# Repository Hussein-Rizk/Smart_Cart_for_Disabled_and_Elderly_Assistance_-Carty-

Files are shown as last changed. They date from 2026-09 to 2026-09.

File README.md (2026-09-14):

# 🛒 Carty — Smart Follow-Me Cart for Disabled & Elderly Assistance

<p align="center">
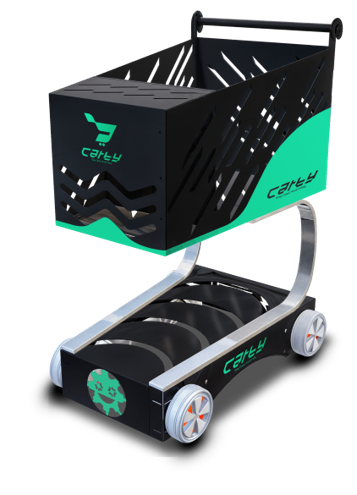
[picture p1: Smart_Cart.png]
  
</p>

<p align="center">
  <b>Stay Close, Move Freely.</b>
</p>

**Graduation Project II — 2025**  
**Mechatronics Engineering Program — Faculty of Engineering, Mansoura University**

**Official Project Title:**  
*Automated “Follow-Me” Cart Using AI and Computer Vision for Disabled and Elderly Assistance*

Carty is an **AI-powered assistive smart cart** designed to improve independence, safety, and convenience for elderly people and individuals with physical disabilities. The system combines **computer vision, gesture recognition, obstacle detection, embedded control, custom electronics, mechanical design, and a mobile-app interface** in a single multidisciplinary prototype.

The cart can recognize its user, respond to hand gestures, follow autonomously, detect nearby obstacles, and also support manual control. A companion app concept extends the system with cart control, battery monitoring, store navigation, and cart-content tracking.

---

## 🎯 Project Goal

The goal was to create a **hands-free mobility and carrying assistant** that reduces the physical effort required for everyday tasks while remaining safe and intuitive to use.

Core objectives included:

- autonomous user following
- hand-gesture interaction
- real-time obstacle detection and avoidance
- manual control when needed
- robust and portable mechanical design
- real-time AI processing on embedded hardware
- modular electronics and custom PCB integration
- battery-powered operation
- user monitoring and control through a mobile interface

---

## ✨ Key Features

### 🤖 AI-Powered Gesture Recognition

The cart uses a camera and **MediaPipe** hand tracking to detect hand landmarks and interpret gestures.

Examples documented in the project include:

```text
Open / Follow gesture → Follow the user
Stop gesture          → Stop the cart
```

MediaPipe was selected because it is lightweight, optimized for real-time operation, and provides **21 hand landmarks** for gesture classification.

### 👕 User / Vest Recognition

A **YOLOv8** model was developed for visual recognition, including vest/clothing detection used to help identify and track the intended user.

The development process included:

```text
Dataset Collection
        ↓
Annotation
        ↓
YOLOv8 Fine-Tuning
        ↓
Data Augmentation
        ↓
Real-Time Testing
        ↓
Jetson Nano Deployment
```

### 👁️ Obstacle Detection & Avoidance

The cart combines:

- IR sensors
- ultrasonic sensors
- camera-based perception

to detect obstacles and improve safe navigation.

### 🎮 Manual Control

Manual control is supported through a **joystick / Arduino Nano control layer**, allowing the system to be operated directly when autonomous control is not appropriate.

### 📱 Mobile App / UI

The documented Carty mobile-app interface includes:

- user registration
- recognition screen
- store mapping
- manual cart control
- automatic/manual mode selection
- speed selection
- battery monitoring
- cart-content monitoring
- item count and cost display
- remote cart control

UI documentation is available in the `UI/` folder.

---

# 🧠 System Architecture

```text
                         ┌─────────────────────┐
                         │       Camera        │
                         └─────────┬───────────┘
                                   │
                                   ▼
                         ┌─────────────────────┐
                         │  NVIDIA Jetson Nano │
                         │ MediaPipe / YOLOv8  │
                         │ Computer Vision     │
                         └─────────┬───────────┘
                                   │ UART
                                   ▼
                         ┌─────────────────────┐
                         │    Arduino Nano     │
                         │    ATmega328P       │
                         └──────┬───────┬──────┘
                                │       │
                   ┌────────────┘       └─────────────┐
                   ▼                                  ▼
          ┌────────────────┐                ┌─────────────────┐
          │ IR / Ultrasonic│                │  Motor Drivers  │
          │    Sensors     │                └────────┬────────┘
          └────────────────┘                         │
                                                   ▼
                                           ┌──────────────┐
                                           │ Wiper Motors │
                                           │   + Wheels   │
                                           └──────────────┘
```

The embedded software also follows a layered structure:

```text
Application Layer
      ↓
HAL — Hardware Abstraction Layer
      ↓
MCAL — Microcontroller Abstraction Layer
```

The project documentation describes UART communication at **9600 baud** between embedded subsystems.

---

# ⚙️ Mechanical Design

The cart was developed through multiple SolidWorks iterations before the final design was selected.

<p align="center">
  
</p>

The design consists of:

- upper storage body
- lower drive chassis
- component enclosure
- curved structural linking members
- threaded support rods
- four wheels
- four wiper motors
- custom motor-wheel couplers
- integrated camera mounting area
- hardware and wiring passages

### Main Materials

| Section | Material / Purpose |
|---|---|
| Lower chassis | Galvanized sheet metal for load-bearing strength |
| Upper side panels | Sheet metal for structural stiffness |
| Electronics enclosure | Wood for lightweight electrical insulation |
| Linking members | Steel for stability and support |
| Couplers | Machined steel |
| Handle | Wood |

The project book documents an overall cart size of approximately **600 × 820 mm** and a prototype mass of approximately **20 kg**.

---

## 🚗 Drive System

The cart uses **four wiper motors**, selected for their high torque, availability, durability, and cost effectiveness.

Documented motor characteristics include:

```text
Rated torque       ≈ 20 Nm per motor
Operating voltage  = 12 V
Operating current  ≈ 4–5 A under load
Number of motors   = 4
```

The design study estimated a maximum supported operating mass of approximately:

```text
62.7 kg
```

for the selected drive configuration.

---

# 🔌 Hardware

Major hardware used in the prototype includes:

| Component | Function |
|---|---|
| NVIDIA Jetson Nano | AI and computer-vision processing |
| Arduino Nano | Motor/sensor control and embedded coordination |
| Camera | User tracking and gesture recognition |
| IR Sensors | Short-range obstacle detection |
| Ultrasonic Sensors | Distance measurement / obstacle detection |
| Wiper Motors | Cart movement |
| Motor Drivers | Direction and PWM speed control |
| Joystick | Manual control |
| Battery | Mobile power source |
| Custom PCBs | Motor control, safety, and control integration |

### Jetson Nano

The project uses the NVIDIA Jetson Nano as the main AI computing platform.

```text
GPU:      128-core Maxwell
Memory:   4 GB LPDDR4
I/O:      USB 3.0, CSI camera, GPIO
```

### Camera

```text
Resolution:      1920 × 1080
Frame rate:      30 FPS
Field of view:   120°
```

### Sensors

**IR Sensors**
- 5 V operation
- short-range obstacle detection
- front and side placement

**Ultrasonic Sensors**
```text
Detection range: 2 cm – 4 m
Operating voltage: 5 V
Accuracy: ±3 mm
```

---

# 🧩 Custom PCB Design

Three custom PCBs were designed as part of the hardware system.

### 1. Motor Driver PCB
Responsible for:
- motor direction control
- PWM-based speed control
- interfacing the Arduino Nano with the motors
- high-current drive operation
- thermal management

### 2. Safety PCB
Designed for:
- protection mechanisms
- power management
- automatic disconnection during faults
- improved electrical reliability

### 3. Nano & Joystick PCB
Integrates:
- Arduino Nano
- joystick input
- motor-control signals
- sensor connections
- Jetson Nano communication
- power distribution
- real-time coordination

PCB design and simulation work included **EasyEDA** and **Proteus**.

---

# 💻 Software & Computer Vision

The software side combines embedded programming with real-time computer vision.

### Main Technologies

```text
Python
OpenCV
MediaPipe
YOLOv8 / Ultralytics
PyTorch
NumPy
Pandas
NVIDIA Jetson Nano
Arduino / ATmega328P
UART
```

### Computer-Vision Pipeline

```text
Camera Feed
    ↓
User / Clothing Recognition
    ↓
Hand Landmark Detection
    ↓
Gesture Classification
    ↓
Movement Command
    ↓
Jetson Nano
    ↓
UART
    ↓
Arduino Nano
    ↓
Motor Control
```

---

# 📱 Carty App UI

The `UI/` folder contains **8 UI images** and the full `ui.pdf`.

The interface concept covers:

### Registration & Recognition
- user registration
- front-camera recognition

### Cart Control
- forward / reverse / left / right
- low / medium / high speed
- manual mode
- automatic mode

### Store Mapping
- navigation interface
- destination / product search concept

### Battery Monitoring
- battery percentage
- remaining operating time

### Cart Content
- number of items
- used cart space
- total cost

The broader project documentation also describes synchronization and remote control through the mobile application.

---

# 🧪 Testing & Validation

The `Testing/` folder documents the project from subsystem testing to complete real-world operation.

### 1. `Assembly Final Project.mp4`
Shows the final mechanical assembly and integration of the cart.

### 2. `Computer Vision Test 1.mp4`
Tests the **Jetson Nano computer-vision / hand-gesture recognition pipeline**.

### 3. `Computer Vision Test 2.mp4`
Further tests gesture recognition and AI behavior under practical conditions.

### 4. `Practical Test.mp4`
Demonstrates the **complete smart cart working as an integrated system**, including recognition and physical cart movement.

Testing documented during the project also included:
- motor load testing
- PWM tuning
- sensor reliability testing
- different lighting environments
- battery/power testing
- hardware/software integration
- computer-vision validation

---

# 📚 Project Documentation

### `Carty.pdf` / `Carty.pptx`
The main project presentation covers:
- project overview and goals
- mechanical design
- hardware
- PCB design
- computer vision
- MediaPipe gesture recognition
- YOLOv8 recognition
- Jetson Nano environment
- embedded architecture
- mobile UI
- system testing

### `Graduation_Project_2_Book/`
Contains the complete Graduation Project II documentation, including:
- literature review
- mechanical design
- fabrication
- hardware implementation
- PCB design
- software integration
- AI and computer vision
- Jetson Nano setup
- ATmega328P architecture
- UI design
- testing
- project management
- cost analysis
- challenges
- future work

### `Add-Ons/`
Contains the final communication and exhibition material:
- banners
- poster
- brochure

---

# 👥 Team

<p align="center">
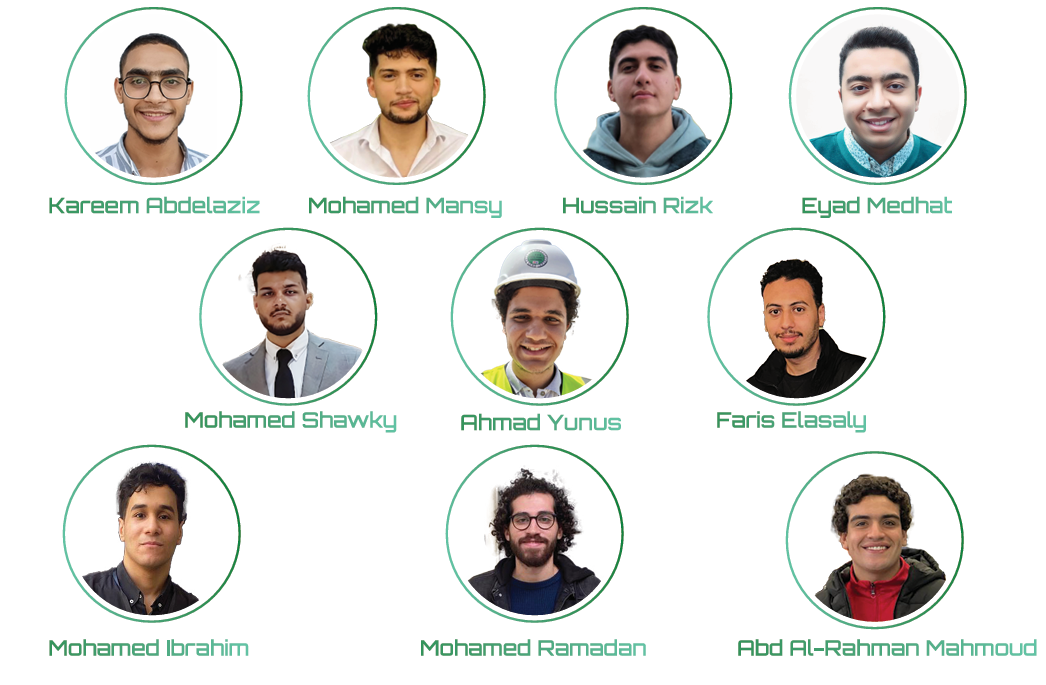
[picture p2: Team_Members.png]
  
</p>

**Project Team**

- Hussain Ahmed Ibrahim Abd Al-Aziz Rizk
- Eyad Medhat Mohamed Abdeljawad
- Mohamed Ahmed Fouad Ahmed Mansy
- Kareem Abdelaziz Ibrahim Abdallah
- Ahmad Mohammad Abdulmajid Yunus
- Mohamed Shawky Shawky Soliman
- Faris El-Sayed Nabeeh Elasaly
- Mohamed Ahmed Ramadan Abd Al-Atty
- Mohamed Ibrahim Abd El-Mawla
- Abd Al-Rahman Mahmoud El-Saeed Mohamed

**Supervisors**
- Prof. Sabry Saraya
- Eng. Ali El-Henidy

---

# 🎓 Project Information

**Project:** Carty — Automated Follow-Me Cart Using AI and Computer Vision for Disabled and Elderly Assistance  
**Type:** Graduation Project II  
**Year:** 2025  
**Academic Year:** 2024–2025  
**Program:** Mechatronics Engineering  
**Faculty:** Faculty of Engineering  
**University:** Mansoura University  

---

## 🚀 What This Project Demonstrates

- Mechanical CAD and fabrication
- Autonomous mobile robotics
- AI and computer vision
- Embedded systems
- Sensor integration
- Motor control
- Custom PCB design
- UART communication
- Edge AI deployment
- Human-machine interaction
- Mobile UI/UX design
- Practical integration and testing

> **Carty** demonstrates how mechanical engineering, embedded electronics, artificial intelligence, and computer vision can be integrated into an assistive robotic system designed around a real human need.

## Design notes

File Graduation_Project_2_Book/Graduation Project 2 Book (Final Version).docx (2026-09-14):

MANSOURA UNIVERSITY

FACULTY OF ENGINEERING

MECHATRONICS ENGINEERING PROGRAM

# Automated “Follow-Me” Cart Using AI and Computer Vision for Disabled and Elderly Assistance

Project Members ID number

Hussain Ahmed Ibrahim Abd Al-Aziz Rizk 803084842

Eyad Medhat Mohamed Abdeljawad 803089397

Mohamed Ahmed Fouad Ahmed Mansy 805771560

Kareem Abdelaziz Ibrahim Abdallah 803089481

Ahmad Mohammad Abdulmajid Yunus 803085462

Mohamed Shawky Shawky Soliman 803089402

Faris El-Sayed Nabeeh Elasaly 806096665

Mohamed Ahmed Ramadan Abd Al-Atty 803084384

Mohamed Ibrahim Abd El-Mawla 803089386

Abd Al-Rahman Mahmoud El-Saeed Mohamed 803084739

Supervisors:

Prof. Sabry Saraya

Eng. Ali El-Henidy

Academic Year: Fall 2024-2025

ACKNOWLEDGMENT

# We would like to express our deepest gratitude to Dr. Sabry Saraya for his continuous guidance and mentorship throughout the project.

# We also thank Eng. Ali El-Henidy for being the consultant and advisor we needed. The recommendations we received were of utmost value and dramatically improved the quality of our project.

# Special thanks to Eng. Ahmed Ibrahim and Eng. Mariam Helal and

# Eng. Khaled Waleed for volunteering their time and effort to assist us with their experience and exceptional quality. We cannot forget our friends and colleagues who provided us with their prior experiences; we thank every single one of you.

# Last but not least, we are profoundly grateful to our families. Their constant encouragement and support during our study years in this faculty have been the driving force behind every success we achieve. For that, we are truly thankful.

# ABSTRACT

The "Automated Follow-Me Cart Using AI and Computer Vision for Disabled and Elderly Assistance" addresses the growing need for accessible and intelligent mobility solutions in an aging society and for individuals with physical disabilities. This project integrates advanced computer vision and artificial intelligence to develop a smart cart capable of autonomously following its user based on intuitive hand gesture recognition. By leveraging deep learning algorithms, the system processes real-time video streams to identify user gestures, ensuring accurate and responsive tracking.

In addition to following the user, the cart incorporates state-of-the-art sensors for obstacle detection and avoidance, promoting safety in crowded or confined spaces. These sensors enable the cart to identify and navigate around obstacles such as people, furniture, or shelves while maintaining a consistent distance from the user. Furthermore, proximity and tracking sensors enhance the cart's ability to adapt to dynamic environments, ensuring reliable operation in diverse settings like homes, hospitals, and supermarkets.

The mechanical design emphasizes durability, portability, and efficiency. It is engineered with robust materials and optimized for lightweight construction, allowing easy maneuverability across various terrains. The integrated motors and power system ensure smooth and energy-efficient operation, while the modular design facilitates maintenance and scalability.

This project represents a multidisciplinary effort that combines mechanical engineering, computer vision, sensor integration, and artificial intelligence to create a user-friendly and accessible solution. By improving the independence and quality of life of disabled and elderly individuals, the Automated Follow-Me Cart contributes to a more inclusive society and demonstrates the transformative potential of modern engineering and technology.

TABLE OF CONTENTS

LIST OF FIGURES

Figure 1.1: Fields that Mechatronics Cover .......................................................................... 16

Figure 3.1: CAD Perspective ................................................................................................ 28

Figure 3.2: Real-View Perspective ........................................................................................ 28

Figure 3.3: Complete Design on SOLIDWORKS ................................................................ 30

Figure 3.4: Lower Part (Bottom View) ................................................................................. 31

Figure 3.5: Lower Part (Top View) ....................................................................................... 31

Figure 3.6: Upper Part of the Cart ......................................................................................... 31

Figure 3.7: The Linking Part ................................................................................................. 32

Figure 3.8: Side View of the Cart .......................................................................................... 32

Figure 3.9: Dimensions of the Cart ....................................................................................... 33

Figure 3.10: Components Used in the Design ....................................................................... 34

Figure 3.11: Back Side of the Upper Part .............................................................................. 35

Figure 3.12: Right Side of the Upper Part ............................................................................. 35

Figure 3.13: Left Side of the Upper Part ............................................................................... 35

Figure 3.14: Base of the Upper Part ...................................................................................... 36

Figure 3.15: Lower Part of the Cart ...................................................................................... 36

Figure 3.16: Connecting Links .............................................................................................. 37

Figure 3.17: Threaded Rods .................................................................................................. 37

Figure 3.18: The Wiper Motor .............................................................................................. 37

Figure 3.19: The Used Motor ................................................................................................ 40

Figure 3.20: Opening of the Component Box ....................................................................... 41

Figure 3.21: Closing of the Component Box ........................................................................ 41

Figure 3.22: The Handle of the Cart ..................................................................................... 43

Figure 3.23: The Wheel and the Coupler .............................................................................. 44

Figure 3.24: Other Side of the Wheel .................................................................................... 44

Figure 3.25: Dimensions of the Motor .................................................................................. 48

Figure 3.26: Wiring of the Lower Part .................................................................................. 49

Figure 4.1: Motor Driver Layout ........................................................................................... 60

Figure 4.2: 3D Model for Motor Driver ................................................................................ 61

Figure 4.3: Schematic View of Motor Driver ........................................................................ 61

Figure 4.4: IR Sensor Layout ................................................................................................ 57

Figure 4.5: Ultrasonic Sensor Layout ................................................................................... 57

Figure 4.6: Camera Used with Jetson Nano .......................................................................... 58

Figure 4.7: Arduino Nano ..................................................................................................... 59

Figure 4.8: Jetson Nano ......................................................................................................... 60

Figure 4.9: Royal Battery 12N9-BS ...................................................................................... 61

Figure 4.10: Jumpers and Wires ............................................................................................ 62

Figure 4.11: Safety PCB Layout ........................................................................................... 63

Figure 4.12: 3D Model for Safety PCB ................................................................................. 64

Figure 4.13: Schematic View for Safety PCB ....................................................................... 65

Figure 4.14: Joystick PCB Layout ........................................................................................ 66

Figure 4.15: 3d Model for Joystick PCB ............................................................................... 69

Figure 4.16: Schematic View for Joystick PCB .................................................................... 69

Figure 5.1: Jetson Nano Interface ......................................................................................... 81

Figure 5.2: ATmega328P ....................................................................................................... 83

Figure 5.3: Camera used with Jetson Nano ........................................................................... 83

Figure 5.4: IR Sensor Both Ways .......................................................................................... 84

Figure 5.5: YOLO V8 Logo .................................................................................................. 87

Figure 5.6: Object detection and classification ex1 .............................................................. 88

Figure 5.7: Object detection and classification ex2 .............................................................. 88

Figure 5.8: Mediapipe logo ................................................................................................... 92

Figure 5.9: Hand landmark points ......................................................................................... 93

Figure 5.10: Follow Me Signaling from Hand Gestures ....................................................... 95

Figure 5.11: Stop Signaling from Hand Gestures ................................................................. 95

Figure 5.12: Jetson Interface ............................................................................................... 103

Figure 5.13: Application Interface ...................................................................................... 109

Figure 5.14: Welcome Page ………..................................................................................... 109

Figure 5.15: Register and Log-in Page ……….................................................................... 110

Figure 5.16: Recognition Page ………................................................................................ 110

Figure 5.17: Store Mapping Page ………............................................................................ 111

Figure 5.18: Cart Control Page ………................................................................................ 112

Figure 5.19: Battery Monitoring Page ………..................................................................... 112

Figure 5.20: Cart Content Page ………............................................................................... 113

LIST OF TABLES

Table 6.1: Timeline Schedule ............................................................................................... 111

Table 6.1: Mechanical Costs ................................................................................................ 113

Table 6.2: Hardware Costs ................................................................................................... 114

Table 6.3: Software Costs .................................................................................................... 115

Table 6.4: Total Costs .......................................................................................................... 115

LIST OF ABBREVIATIONS

AI Artificial Intelligence

PCB Printed Circuit Board

AC Alternative Current

DC Direct Current

CAD Computer-Aided Design

IR Infrared

LIDAR Light Detection and Ranging

UART Universal asynchronous receiver / transmitter

BMS Battery Management System

GPU Graphics processing unit

Chapter 1 Introduction

# 1. Introduction

Mobility challenges faced by elderly individuals and those with physical disabilities can significantly impact their independence and overall quality of life. Activities that many take for granted, such as carrying groceries, moving objects, or navigating crowded spaces, can be overwhelming without proper assistance. Recognizing these challenges, our graduation project focuses on creating an intelligent solution—the Automated Follow-Me Cart Using AI and Computer Vision for Disabled and Elderly Assistance. This innovative cart is designed to enhance mobility, safety, and convenience for users, leveraging modern technologies to address a growing societal need.

The project was developed within the Mechatronics Engineering Department, a multidisciplinary field that integrates mechanics, electronics, computer science, and control engineering to design and create intelligent systems. The department fosters innovation by encouraging students to apply their knowledge to solve real-world problems, such as those tackled in this project. As shown in Figure 1.1, the Mechatronics Department emphasizes the intersection of these core engineering disciplines, making it an ideal environment for developing complex systems like the Automated Follow-Me Cart.

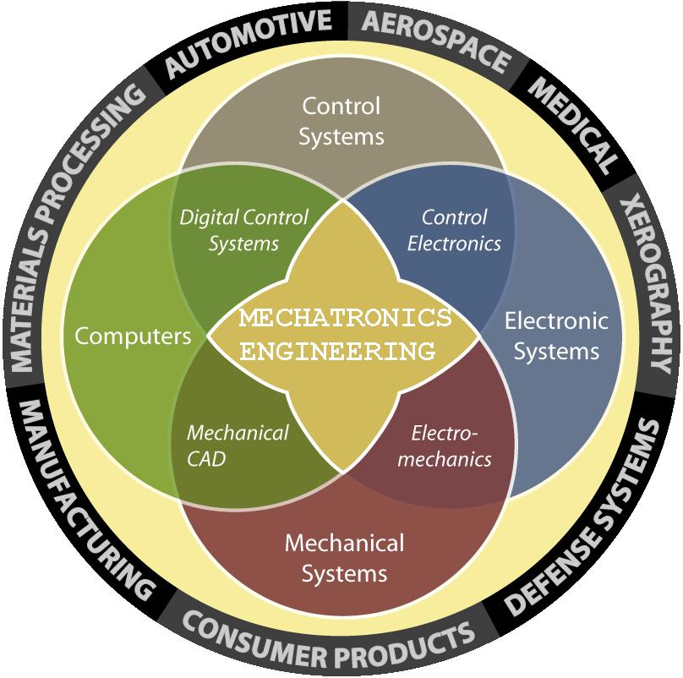
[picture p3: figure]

In this section, we will introduce the project’s goals, its key components, and the methodologies used in its design and implementation. We aim to provide a comprehensive overview of how the cart integrates advanced technologies to address practical challenges in assistive mobility.

Figure 1.1 Feilds that Mechatronics cover

## 1.1 Background and Motivation

The increasing global aging population and the prevalence of physical disabilities underscore the need for assistive technologies. According to recent studies, mobility aids such as wheelchairs and walkers have limitations in providing seamless, independent mobility. These devices often require significant human effort or assistance from caregivers. This creates a demand for smarter, more autonomous systems that can adapt to the user’s needs and environment.

Our project addresses these issues by combining artificial intelligence, computer vision, and mechanical design. The cart is specifically designed to follow the user autonomously, carry loads, and avoid obstacles in real-time. This blend of technologies ensures that users can move independently with minimal effort, promoting inclusivity and improving their quality of life.

## 1.2 Overview of the Project

The Automated Follow-Me Cart integrates multiple disciplines, including mechanical engineering, electronics, artificial intelligence, and computer vision. The primary objective is to create a cart that can follow a user intuitively, avoiding obstacles and ensuring smooth operation across different terrains.

The project’s mechanical structure was designed using SolidWorks, a powerful 3D CAD software widely used for engineering design and simulation. SolidWorks allowed the team to create a lightweight yet robust cart body that ensures durability and reliability. The design was optimized for weight distribution, easy maneuverability, and integration of electronic components such as sensors, motors, and processing units.

Key hardware components of the cart include:

- Four Motors: These provide stable and smooth movement, allowing the cart to traverse various surfaces with ease.
- Two Motor Drivers: Essential for precise control of the motors, ensuring the cart responds accurately to commands.
- Three Infrared (IR) Sensors: These sensors detect nearby obstacles and ensure real-time obstacle avoidance.
- A Camera: Used for real-time hand gesture recognition, the camera enables the cart to interpret and respond to user commands effectively.
- NVIDIA Jetson Platform: Serving as the AI computation unit, this platform processes the camera’s input for gesture recognition and controls the cart’s movement.
- Arduino Nano: A versatile microcontroller that handles auxiliary functions and integrates seamlessly with the other components.
- A Rechargeable Battery: Ensures the cart operates independently without the need for external power, providing portability and convenience.

## 1.3 Scope and Objectives

The project aims to address the following key objectives:

1. Mobility Assistance: Provide a hands-free, intuitive solution for elderly and disabled individuals to carry objects and navigate various environments.
2. Obstacle Avoidance: Ensure safety by integrating sensors and algorithms to detect and avoid obstacles in real-time.
3. Gesture Recognition: Implement an AI-based hand gesture recognition system for seamless user interaction.
4. Durability and Portability: Design a lightweight, robust mechanical structure capable of withstanding daily use across different terrains.
5. Energy Efficiency: Optimize power usage to ensure long battery life while maintaining performance.

By achieving these objectives, the project contributes to the growing field of assistive technology and promotes greater independence for users.

## 1.4 Significance of the Project

This project demonstrates the potential of engineering and technology to create solutions that address real-world challenges. The Automated Follow-Me Cart is more than just a mobility aid; it is a step toward a more inclusive society where technology bridges the gap for those with physical limitations. By combining AI, computer vision, and mechanical engineering, the cart offers a unique and practical solution to mobility challenges faced by a significant portion of the population.

Moreover, the cart’s modular and scalable design makes it a promising prototype for further development and commercialization. Its potential applications extend beyond individual users to include use cases in hospitals, care facilities, and retail environments, where similar functionality could improve operational efficiency and user experience.

## 1.5 Methodology Overview

The development of the Automated Follow-Me Cart involved a multidisciplinary approach, combining the following methodologies:

1. Mechanical Design: Using SolidWorks, the cart body was designed to optimize weight distribution, durability, and ease of assembly. Stress analysis and simulations were conducted to ensure structural integrity.
2. Hardware Integration: The cart includes multiple PCBs, motor drivers, IR sensors, a camera, and a Jetson AI platform. Each component was carefully selected and integrated to ensure compatibility and efficient operation.
3. Software Development: Custom algorithms for hand gesture recognition were developed and deployed on the NVIDIA Jetson platform. The Arduino Nano was programmed for auxiliary tasks such as motor control and sensor data processing.
4. Testing and Validation: The system was tested in various environments to ensure reliable operation. Real-world scenarios were simulated to validate the cart’s ability to follow the user, avoid obstacles, and respond to gestures.

By combining innovative design and advanced technologies, the Automated Follow-Me Cart showcases the power of engineering to solve real-world problems and improve lives.

## 1.6 Objectives

The primary objectives of the Automated “Follow-Me” Cart project are as follows:

1. Enhance Mobility Assistance: To design and build an intelligent, hands-free cart that autonomously follows users, allowing elderly and disabled individuals to carry groceries, personal items, or other objects with minimal effort, promoting independence in daily activities.
2. Real-Time Obstacle Avoidance: To integrate sensors (infrared and camera-based) and algorithms that enable the cart to detect and avoid obstacles in real-time, ensuring safe navigation through crowded or obstructed environments.
3. Implement Gesture Recognition for Seamless Interaction: To develop an AI-powered hand gesture recognition system using computer vision, enabling users to control the cart with simple, intuitive gestures without requiring physical touch or manual intervention.
4. Optimize Durability and Portability: To design a lightweight, yet robust mechanical structure capable of withstanding daily wear and tear across various terrains, ensuring the cart's longevity and ease of use in different environments.
5. Ensure Energy Efficiency and Long Battery Life: To optimize the cart's power consumption, enabling the system to operate for extended periods on a single charge while maintaining performance across all functions.
6. Provide a Scalable, Modular Design: To create a cart with a flexible design that can be further developed or adapted for other applications, including use in hospitals, care facilities, and retail spaces, extending its impact beyond individual mobility assistance.

By achieving these objectives, the Automated “Follow-Me” Cart will not only enhance the quality of life for elderly and disabled individuals but also serve as a practical solution that demonstrates the potential of modern technologies in assistive mobility.

Chapter 2 Literature Review

# 2. Literature Review

The development of the Automated “Follow-Me” Cart leverages several established and emerging technologies. This chapter reviews relevant research and existing technologies that form the foundation of the project. We examine the intersection of mobility assistance, robotics, artificial intelligence (AI), computer vision, and sensor technologies. By exploring these fields, we aim to better understand how various components can be integrated to design a functional, autonomous, and user-friendly assistive cart.

## 2.1 Mobility Aids and Assistive Technologies

The global aging population and the increasing prevalence of physical disabilities necessitate the development of mobility aids and assistive technologies. According to the World Health Organization (WHO), approximately 15% of the global population lives with a disability, and a significant portion of these individuals’ experiences mobility challenges (WHO, 2020). Traditional mobility aids, such as wheelchairs, walkers, and scooters, help improve mobility, but they come with limitations, such as dependency on manual operation, difficulties in navigating through crowded spaces, and lack of flexibility in adapting to various environments.

Research in assistive technologies has increasingly focused on reducing the dependency on caregivers and enhancing user autonomy. Early work in assistive robotics, such as the development of intelligent wheelchair systems, demonstrated that mobility could be enhanced through automation and sensor integration. For instance, studies by Akgün and Öztürk (2018) focused on developing autonomous navigation systems for electric wheelchairs, using sensors to detect obstacles and avoid collisions. These early developments laid the groundwork for the more advanced autonomous systems that are central to the Follow-Me Cart project.

## 2.2 Autonomous Mobile Robots (AMRs)

Autonomous mobile robots (AMRs) are robotic systems capable of performing tasks without human intervention. These robots are used in various industries, such as warehousing, agriculture, and healthcare. The concept of AMRs has evolved significantly, with advancements in AI, machine learning, and real-time data processing. According to Brooks (1986), the key challenge for AMRs lies in enabling them to navigate dynamic environments, such as crowded spaces or uneven terrain, while ensuring safety and reliability.

AMRs typically rely on a combination of sensors, including infrared (IR) sensors, ultrasonic sensors, cameras, and LIDAR (Light Detection and Ranging), to perceive their surroundings. The Follow-Me Cart integrates IR sensors for short-range obstacle detection and a camera for gesture recognition, both of which are critical for the cart’s autonomous functionality. Studies like those of Bhattacharya et al. (2017) on autonomous service robots emphasize the importance of sensor fusion for robust navigation in complex environments. The integration of multiple sensing modalities allows the Follow-Me Cart to detect and avoid obstacles effectively, even in crowded retail or indoor environments.

## 2.3 Hand Gesture Recognition

One of the most innovative aspects of the Follow-Me Cart is its use of AI-based hand gesture recognition. Gesture recognition systems have gained popularity in recent years due to their intuitive user interaction capabilities, particularly in applications where traditional input methods (e.g., buttons, joysticks) are less suitable. Gesture recognition leverages computer vision techniques to analyze and interpret hand movements, translating them into commands for various devices.

Several studies have explored the use of hand gesture recognition for controlling robots and assistive devices. A prominent approach uses machine learning algorithms to identify and classify gestures. For instance, Hossain et al. (2020) explored the use of deep learning techniques for recognizing hand gestures to control robotic arms. Similarly, work by Sadeghi et al. (2019) demonstrated the effectiveness of convolutional neural networks (CNNs) in recognizing hand gestures for controlling robotic systems in real-time. By using a camera for hand gesture recognition, the Follow-Me Cart employs these principles to create a seamless user interface, enabling individuals with mobility impairments to interact with the cart intuitively and without physical contact.

## 2.4 Obstacle Detection and Avoidance

Obstacle detection and avoidance are fundamental to ensuring the safety and smooth operation of autonomous systems, especially in dynamic environments. The Follow-Me Cart utilizes infrared (IR) sensors to detect nearby obstacles and adjust its path accordingly. Obstacle detection algorithms rely on real-time sensor data to calculate the cart’s position relative to obstacles and modify its movement.

Many autonomous vehicles and mobile robots use a combination of sensor types for enhanced perception. LIDAR and ultrasonic sensors are commonly used in large-scale autonomous systems, while smaller robots and assistive devices often rely on IR or ultrasonic sensors due to their affordability and simplicity. Work by Yang et al. (2018) in the field of mobile robotics highlights the importance of sensor fusion, combining data from multiple sensors to create a comprehensive map of the environment and enable reliable obstacle avoidance. The Follow-Me Cart integrates IR sensors to provide real-time data, allowing the cart to avoid obstacles such as people, shelves, or other objects in its path.

A key challenge in obstacle avoidance is ensuring the cart can operate in environments where obstacles are constantly changing, such as busy retail stores or crowded walkways. Dynamic path planning algorithms, such as those described by Kamal et al. (2019), can help the cart adapt to changing conditions by continually recalculating its optimal path in response to newly detected obstacles. These algorithms are a crucial component of the Follow-Me Cart’s software system.

## 2.5 AI and Machine Learning in Robotics

Artificial Intelligence (AI) and machine learning (ML) have revolutionized the field of robotics, enabling autonomous systems to learn from their environments, adapt to new situations, and improve performance over time. The Follow-Me Cart utilizes AI techniques for hand gesture recognition and to enhance its overall decision-making capabilities.

Machine learning algorithms, particularly deep learning models such as convolutional neural networks (CNNs), are widely used for image and pattern recognition tasks. In the context of gesture recognition, CNNs are particularly effective in identifying and classifying hand gestures based on visual input. Work by Sharma et al. (2020) demonstrated how CNNs could be used for robust gesture recognition, even in real-time applications with limited computing resources. The “Follow-Me” Cart uses the NVIDIA Jetson platform, which is optimized for running AI algorithms, to process the camera's input and interpret hand gestures. This allows the cart to follow user commands in a highly responsive and accurate manner.

Beyond gesture recognition, AI and machine learning can also be used to optimize the cart’s navigation. Reinforcement learning, a branch of machine learning focused on decision-making and reward optimization, can be applied to improve obstacle avoidance and path planning. This approach allows the cart to “learn” from its environment by continually refining its ability to navigate and follow the user in real-time.

## 2.6 Integration of Hardware and Software

The integration of hardware and software is a critical aspect of any robotics project. The Follow-Me Cart brings together various components, including the mechanical body, motors, sensors, microcontrollers, and AI computation unit, to create a seamless, functional system. The integration of these components requires careful consideration of compatibility, power requirements, and performance optimization.

The mechanical design of the cart, created using SolidWorks, ensures that the components are housed securely and that the cart is both lightweight and durable. The motors, motor drivers, and microcontrollers are selected based on their ability to work together efficiently, while the sensors and camera are chosen for their reliability in detecting obstacles and recognizing gestures.

The software system, which includes custom algorithms for hand gesture recognition, obstacle avoidance, and motor control, is deployed on the NVIDIA Jetson platform. This platform offers the computational power necessary for running AI-based algorithms in real-time. The Arduino Nano microcontroller handles auxiliary functions, such as motor control and sensor data processing, enabling smooth integration with the Jetson platform.

## 2.7 Conclusion

The literature review highlights the existing research and technologies that have contributed to the development of the Automated Follow-Me Cart. By combining insights from mobility assistance, autonomous robots, hand gesture recognition, and obstacle avoidance, the project aims to create a practical solution that addresses the mobility challenges faced by elderly and disabled individuals. The integration of AI, computer vision, and mechanical design offers a comprehensive approach to assistive technology, ensuring that the cart is both functional and user-friendly. As the project progresses, the insights from this literature review will guide the continued development of the system, with an emphasis on safety, usability, and efficiency.

Chapter 3 Mechanical Design

# 3. Mechanical Design

Figure 3.1 illustrates the CAD model of the Automated Follow-Me Cart, meticulously designed using SolidWorks. The model showcases the cart’s structural components, ensuring optimal weight distribution and durability. Each part has been designed and assembled to accommodate the hardware integration and user-specific functionalities, such as obstacle detection and gesture recognition modules. In contrast, Figure 3.2 presents the real-world perspective of the finalized project, demonstrating the seamless transition from the conceptual CAD design to the physical prototype. The real-view image highlights the successful implementation of the design, emphasizing its robust construction, compactness, and aesthetic appeal, which aligns with the project's goal of providing a practical and user-friendly mobility solution.

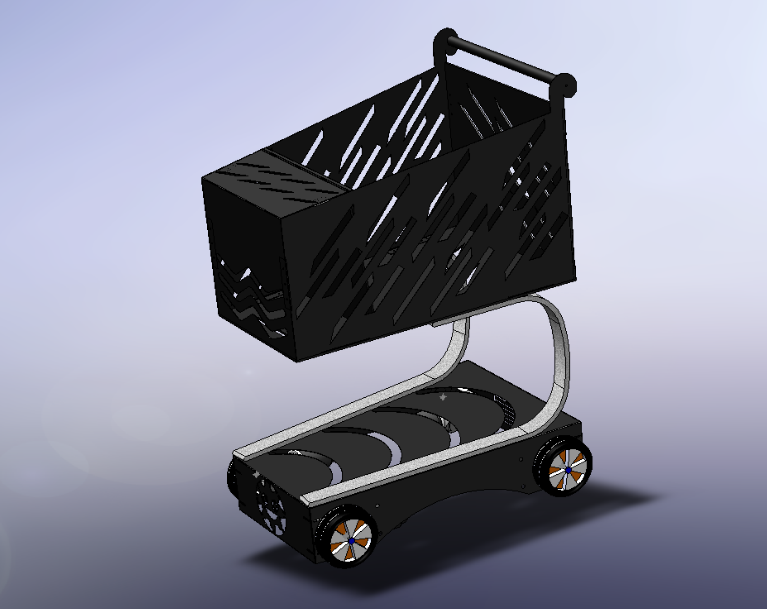
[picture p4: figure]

Figure 3.2 Real-View Perspective

Figure 3.1 CAD Perspective

The mechanical design sector is a critical component that encompasses the development and optimization of the cart's structural integrity and functionality. This chapter delves into the design principles, the parts used, materials selection, and fabrication methods employed to create a robust and efficient mechanical system.

Throughout the design process, we prioritized simplicity and efficiency, striving to minimize complexity while ensuring each component contributes effectively to the overall performance of the cart. The interplay of various mechanical parts, including the upper and lower bases, connecting flanges, and fasteners, was carefully considered to facilitate seamless operation and ease of assembly.

We faced several challenges, particularly in achieving precise angles and dimensions for the connecting components. These challenges required innovative solutions and iterative design adjustments to ensure structural stability and functionality. By employing advanced CAD software, we were able to visualize and refine our designs, leading to optimized mechanical solutions tailored to our project's specific needs.

In this chapter, we will explore the detailed design considerations, and the methodologies adopted to overcome design challenges, ultimately resulting in a cohesive and effective mechanical design.

## 3.1 The Design

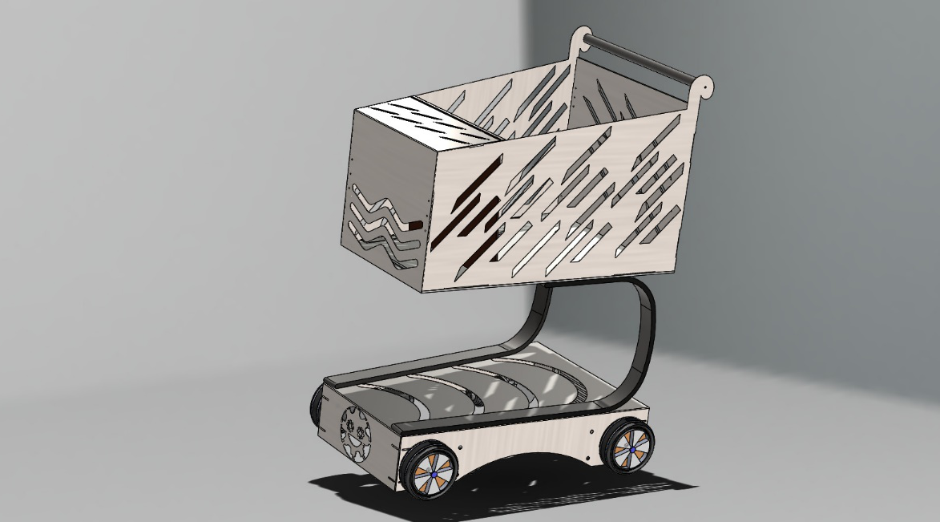
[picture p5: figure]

The complete design was developed using SolidWorks software, as shown in Figure 3.3, allowing our mechanical team to efficiently manage and finalize the entire design process. This CAD program enabled us to ensure that each component could be assembled seamlessly during fabrication. We carefully selected the appropriate dimensions for all parts and made necessary cuts or fixtures to guarantee the optimal functionality of the cart. The detailed CAD model in Figure 3.3 demonstrates the integration of structural and mechanical components, ensuring that the design meets the project's functional and practical requirements.

Figure 3.3 Complete Design on SOLIDWORKS

### 3.1.1 Material Selection for the Prototype

In the development of our prototype, we carefully selected a variety of materials tailored to the specific functions of each component, enhancing overall efficiency.

1. The lower section of the cart, as illustrated in Figure 3.4 (bottom view) and Figure 3.5 (top view), bears the majority of the weight and houses the motors and wheels. This section is constructed from sheet metal, a material chosen to ensure maximum strength and stability under heavy loads. The bottom view in Figure 3.4 highlights the placement of the motors and wheels, while the top view in Figure 3.5 provides a clear perspective of how the components are securely mounted to maintain structural integrity and efficient functionality.

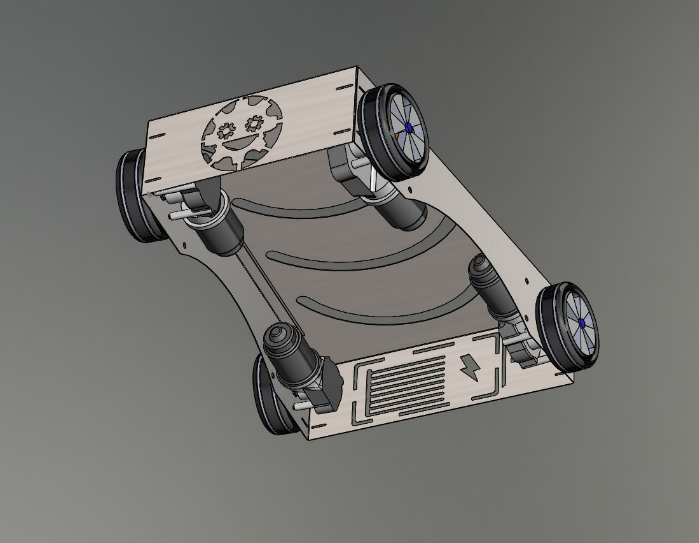
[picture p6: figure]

Figure 3.5 Lower part Top View

Figure 3.4 Lower part Bottom View

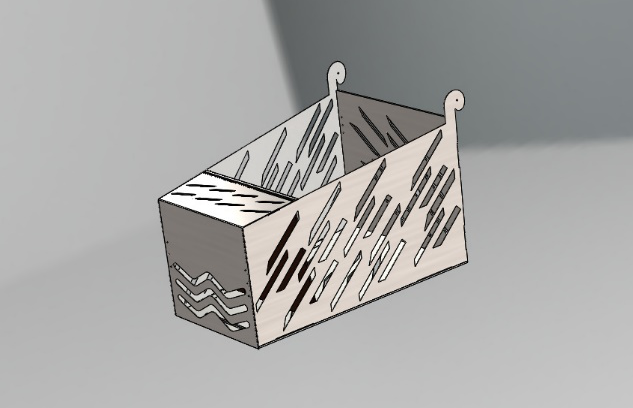
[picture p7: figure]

2. The upper section of the cart, as shown in Figure 3.6, is comprised of four distinct parts. The two side panels, made from sheet metal, provide additional stiffness to the structure, enhancing its durability. The remaining components are crafted from wood, offering a lightweight yet sturdy platform for securing the electrical components. This combination of materials ensures the safe and organized placement of electronic systems, minimizing the risk of electrical issues and prioritizing user safety.

Figure 3.6 The Upper Part of the Cart

3. The linking part, as depicted in Figure 3.7, serves to facilitate support between the upper and lower sections of the cart. To achieve this, we incorporated curved steel welded rods, which provide strength and flexibility, along with two screws to securely fasten the front part of the cart. This design ensures a stable connection between the sections, maintaining structural integrity while accommodating the mechanical and functional requirements of the cart.

Figure 3.7 The Linking Part

4. A holder was integrated to allow for the organized routing of wires and connections between the upper and lower sections. Figure 3.8, the side view of the cart, provides an overall perspective of how the sections are structured and connected, highlighting the streamlined design that accommodates the wiring setup.

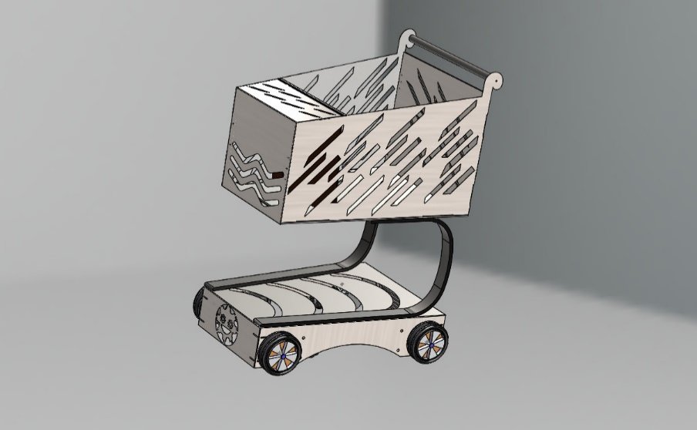
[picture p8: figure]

Figure 3.8 The Side View of The Cart

### 3.1.2 Designing the dimensions

Regarding our prototype, we conducted an analysis of industry-standard carts and found that they typically have a load capacity of 100 to 150 kg, with the cart's weight ranging from approximately 16 to 20 kg. Additionally, the interior volume of these carts spans from 60 to 150 liters, effectively accommodating the intended load.

Our project dimensions, as detailed in Figure 3.9, are 600 × 820 mm with a weight of 20 kg, which aligns closely with market standards. In selecting these dimensions, we considered various specifications, including the average height of an adult user, to ensure optimal usability and comfort. This consideration is essential for facilitating ease of access and maneuverability.

To maximize the storage capacity for user purchases, we designed the cart to be highly user-friendly. The hardware component box is strategically positioned at the front of the cart, allowing for increased storage space both within the cart and above the base. This thoughtful arrangement enhances the cart's functionality, ensuring that users can efficiently organize and access their items during transport.

Figure 3.9 Detailed View for the dimensions of the cart

## 3.2 Mechanical components

During the design process, we prioritized simplifying fabrication by creating a model that required the fewest possible components while focusing solely on those essential for optimal functionality. This careful selection allowed us to streamline manufacturing, reduce costs, and minimize assembly time. All parts were meticulously designed using advanced CAD (Computer-Aided Design) software, enabling precise 3D modeling and early identification of potential design flaws. This approach ensured that every component included played a crucial role, eliminating unnecessary elements that could complicate assembly or increase weight.

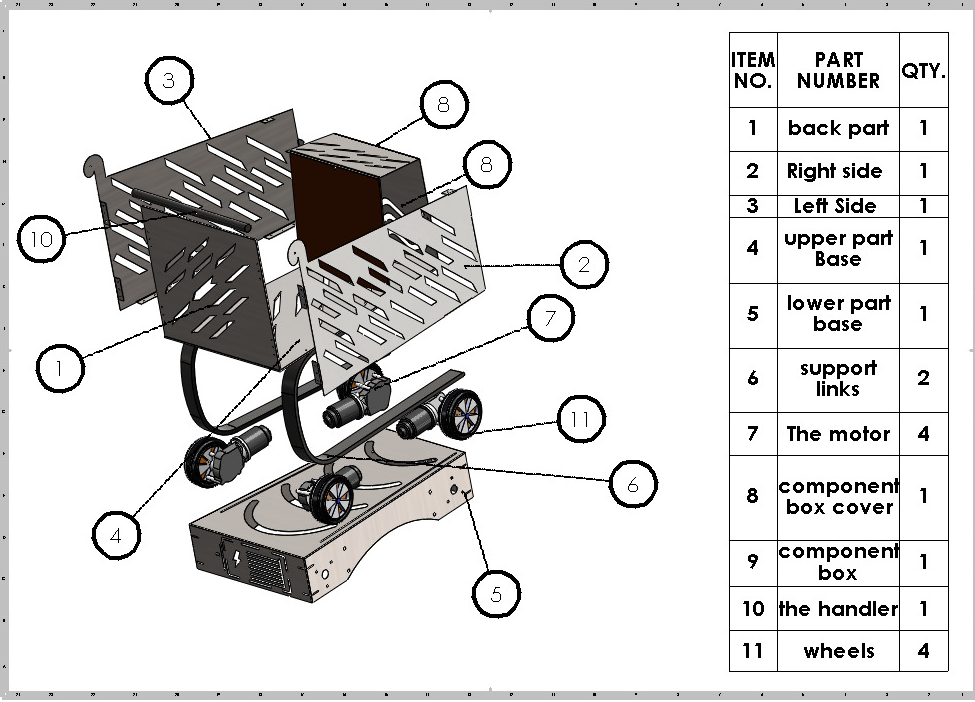
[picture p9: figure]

In addition to the primary components, we incorporated various fasteners, corners, spacers, nuts, and couplers to guarantee robust assembly and reliable performance. Figure 3.10 provides a detailed description of the components used in the design, showcasing the high-quality fasteners securing connections between parts, corners and spacers maintaining proper alignment and spacing, and motor couplers specifically designed to create a secure connection with the wheels, facilitating efficient power transfer. By adopting this focused design strategy, we created a streamlined and efficient model that meets user needs while remaining easy to assemble and maintain, ultimately enhancing performance and contributing to a more sustainable manufacturing process.

Figure 3.10 detailed description for the components used

### 3.2.1 Back Part

For the rear and base sections of the upper part, we selected wood as the primary material due to its insulating properties. This choice allows us to house the necessary hardware components while strategically incorporating cuts to minimize weight, thereby enhancing the cart's mobility and ease of control. Figure 3.11 presents the back side of the upper part, providing a clear view of how the wood material is utilized to securely house the components while maintaining a lightweight and efficient design.

The rear component features a thickness of 4 mm, with dimensions of 350 mm x 400 mm.

Figure 3.11 Back Side of the Upper Part

### 3.2.2 Right Side

The left and right sides of the upper section are constructed from 1 mm thick sheet metal, featuring flanges that securely connect the components. These sides also incorporate cuts to further reduce weight without compromising structural integrity. Figure 3.12 illustrates the right side of the upper part, while Figure 3.13 shows the left side, both highlighting the precise design and the strategic cuts made to minimize weight. To accurately design the sides, we created individual drawings for each part to accommodate the specific angles used in the base of the upper section. For more details, please refer to section 3.2.3, which discusses the upper part's base.

Figure 3.12 The Right Side of the Upper Part

Figure 3.13 The Left Side of the Upper Part

### 3.2.3 Upper Part Base

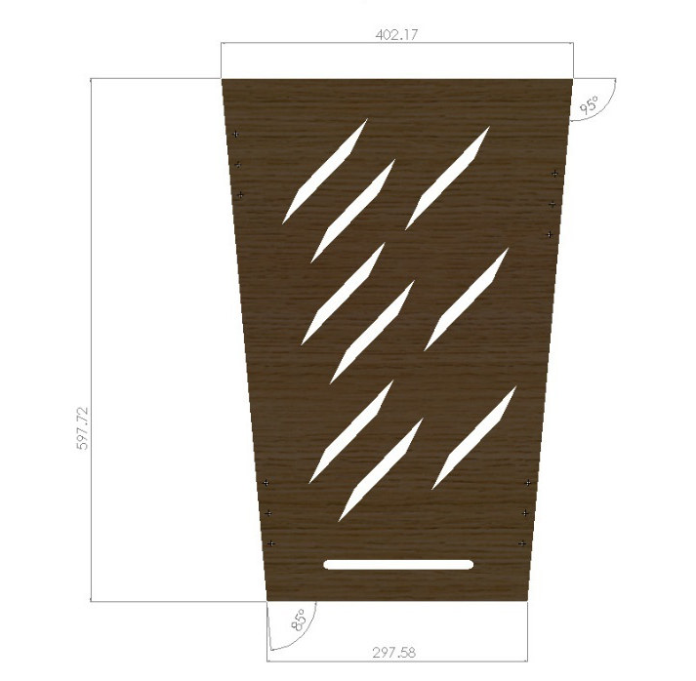
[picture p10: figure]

The base of the upper section is designed in accordance with the dimensions specified in Figure 3.14. We incorporated angles to enhance the smooth movement and overall functionality of the cart. Additionally, a cut was included at the end of the part to create a pathway for the wires that connect the control systems between the upper and lower sections of the cart.
During the design phase of the base of the upper part of the cart, we faced several challenges, primarily due to the angles of the sheet metal used. These angles complicated the dimensioning of the connecting flanges and the alignment of other components, which was crucial for ensuring structural integrity and functionality.
One of the main difficulties was achieving precise measurements for the flanges, as the angles introduced complexity in both the cutting and assembly processes. Misalignment could lead to structural weaknesses, affecting the overall performance of the cart. To address this issue, we utilized advanced CAD software to create detailed models that accurately represented the dimensions and angles. This allowed us to visualize the assembly before physical fabrication, reducing the risk of errors.

Figure 3.14 The Base of the Upper Part

We also collaborated closely with our fabrication team to ensure that the manufacturing processes could accommodate the specific angles and dimensions we had devised. Their insights were invaluable in adjusting our designs to meet practical constraints, allowing for smoother assembly and enhanced stability.

### 3.2.4 Lower Part Base

For the base of the lower section, we selected galvanized steel with a thickness of 1.5 mm to ensure it can withstand the total weight of the cart, including the motors, while maintaining structural integrity under various conditions. We integrated corner supports between the sides of the base to prevent widening gaps and enhance stability. The design features an access box that opens from the bottom and closes from the top (as illustrated in Figure 3.15, shown in an inverted position for clarity), allowing users to utilize the space between the upper and lower sections as additional storage.

To optimize the weight of the lower part without compromising strength, we incorporated various shapes and strategic cuts for wire routing from the upper section to the motors.

Figure 3.15 The Lower part of the Cart

The sides were meticulously measured to accommodate the specifications of the motors, ensuring they are securely mounted to minimize vibrations that could affect the cart's maneuverability. Each motor is positioned to maintain an equal distance from the ground across all wheels.

### 3.2.5 Support Links

For connecting the two parts together, we used sheets made of steel welded in the shape of an arc to give the cart a smooth look, in addition to providing stability and support. Figure 3.16, "Connecting Links," illustrates this arc-shaped design. In addition to this, we used three screws to secure the front of the cart, preventing vibrations and ensuring it stays in place during maneuvering. Figure 3.17, "Threaded Rods," shows the threaded rods used to secure the structure and reinforce its alignment. We also incorporated a third steel guide to carry the wires through the path from the upper to the lower part, ensuring proper cable management throughout the cart's design.

Figure 3.17 Threaded Rod

Figure 3.16 Connecting Links

### 3.2.6 The Motor

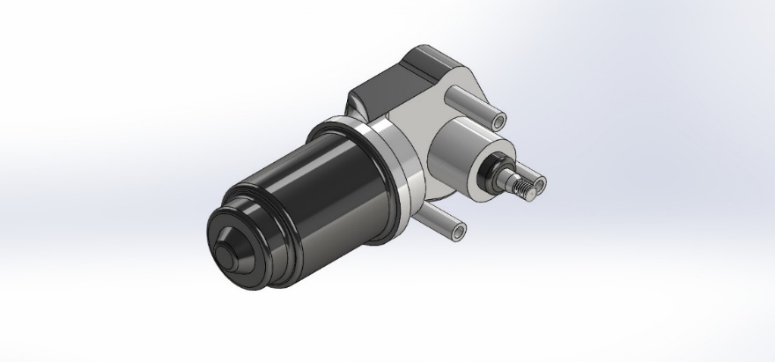
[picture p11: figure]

While searching for a motor for our project, the choice of a wiper motor was pivotal due to its specific operational characteristics and suitability for our design requirements. The wiper motor is primarily used in automotive applications to control the windshield wipers, which means it is engineered for durability and consistent performance under varying conditions. Figure 3.18, "The Wiper Motor," illustrates the motor selected for our project, highlighting its compact design and robustness, which align perfectly with the cart’s functional needs.

Figure 3.18 The Modeled Motor

### 3.2.7 Methodology of searching

For the methodology to select the motor we had searched for some criteria as:

1. Torque and Power: Wiper motors are designed to deliver sufficient torque to overcome the resistance encountered during operation. This characteristic makes them ideal for applications requiring reliable movement, such as driving wheels in our design the model we used gives total Torque of

T-total = 4×20 = 80 Nm

2. Compact Size: The compact nature of wiper motors allows for easy integration into our project without adding excessive weight or bulk. This was particularly important in maintaining the overall design aesthetics and functionality of the cart.
3. Cost-Effectiveness: Wiper motors are generally cost-effective, making them a budget-friendly option for our project. This allowed us to allocate resources effectively while still ensuring high-quality components.
4. Availability: Wiper motors are widely available and can be sourced easily from various suppliers. This accessibility facilitated timely procurement and reduced potential delays in the project timeline.
5. Versatility: The design of wiper motors allows for versatility in mounting and operation. We were able to adapt the motor's configuration easily to fit our specific mechanical setup, ensuring optimal performance.
6. Robustness: Designed to withstand harsh environmental conditions, wiper motors exhibit excellent resilience against moisture and debris. This robustness is crucial for the longevity of our project, especially if it is to be used in varying operational environments.

By selecting a wiper motor, we ensured that our project not only met the required performance standards but also maintained efficiency and reliability throughout its operational life. The combination of these factors made the wiper motor an optimal choice for our mechanical design, aligning perfectly with our project goals.

We also calculated the maximum weight it can handle to be considered while using the cart:

- F = T-total / r

F = 80 / 0.13 ≈ 615.38 N

Knowing that the wheels we used are of 0.13 m radius

Convert the total force into mass:

- m = F / g

then, m = 615.28 / 9.81 = 62.7 kg

So, we can conclude that with motors of 20 Nm torque each, the cart's maximum weight is approximately 62.7 kg for the motors to operate effectively. Figure 3.19, "The Used Motor," provides a visual representation of the motor chosen, demonstrating its capacity and design tailored to handle the cart's weight while ensuring optimal performance.

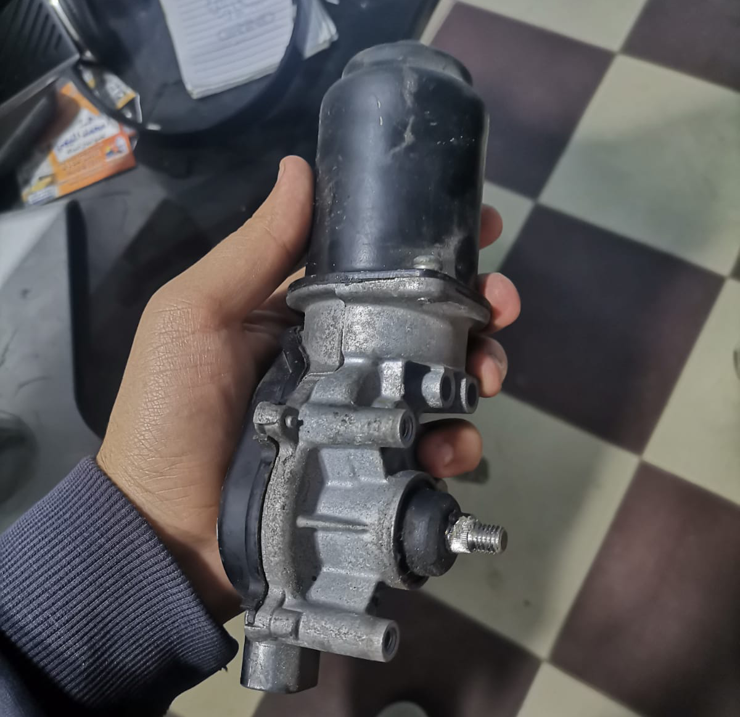
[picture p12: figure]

Figure 3.19 The Used Motor

### 3.2.8 The Component Box Cover

The inclusion of the component box cover in our design was driven by the need for accessibility and efficient maintenance of the hardware. This cover serves several crucial functions that enhance both the functionality and usability of the cart. Figure 3.20, "Clarifying the Opening of the Component Box," illustrates the design for easy access to the hardware inside, while Figure 3.21, "Clarifying the Closing of the Component Box," shows how the cover securely closes to protect the components, ensuring both safety and convenience for the user.

1. Ease of Access: The component box cover allows for quick and easy access to the internal components of the cart. This design feature is particularly beneficial for troubleshooting, repairs, and routine maintenance. By simplifying access, we reduce the downtime associated with addressing technical issues.

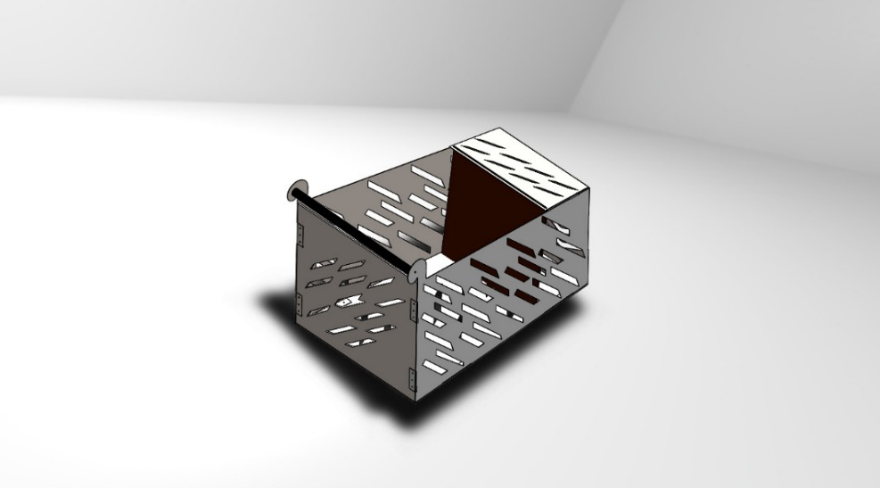
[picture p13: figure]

Figure 3.20 Clarifying the opening of the component box

Figure 3.21 Clarifying the closing of the component box

2. Organized Storage: By compartmentalizing the hardware within the component box, we created a designated space that separates the electronic components from the rest of the storage area. This organization minimizes the risk of damage to sensitive components and keeps everything tidy, making it easier to locate specific parts when needed.
3. Facilitated Maintenance: Regular maintenance is essential for ensuring the longevity and performance of the cart. The component box cover allows users to quickly inspect, clean, or replace components without requiring extensive disassembly of the entire system. This ease of maintenance encourages proactive care and enhances the overall reliability of the cart.
4. Protection from Environmental Factors: The cover also serves to protect the internal components from dust, moisture, and other environmental factors that could potentially compromise their functionality. By shielding the components, we enhance their durability and reduce the likelihood of failures caused by external influences.
5. User-Friendly Design: The thoughtful design of the component box cover contributes to an overall user-friendly experience. Whether for maintenance staff or end-users, the ability to easily access and manage the components fosters confidence in the system's reliability and performance.

### 3.2.9 The Component Box

The component box is a critical element of our design, meticulously crafted to securely house all essential components of the cart. Its thoughtful design not only provides structural integrity but also facilitates optimal organization and insulation between different hardware elements.

- Design Features and Functionality
1. Three-Shelf Structure: The component box features three distinct shelves, each designed to hold specific components securely. This tiered arrangement maximizes space efficiency while ensuring that each component is easily accessible. The vertical layout allows for organized storage, preventing clutter and confusion.
2. Material Selection: Each shelf is constructed from high-quality wood, chosen specifically for its insulating properties. Wood serves as an effective insulator, reducing the risk of electrical interference between components. This is particularly important for maintaining the integrity of sensitive electronics, ensuring reliable performance.
3. Optimal Component Placement:
  - Top Shelf: The top shelf is designated for the camera, which is essential for capturing real-time data and providing visual feedback. Its elevated position allows for an unobstructed field of view, enhancing the functionality of the cart.
  - Middle Shelf: Below the camera, the middle shelf houses the various controllers. This strategic placement ensures that the controllers are easily accessible for adjustments or troubleshooting while remaining insulated from the camera above.
  - Bottom Shelf: The bottom shelf is reserved for the batteries, providing a stable base for the power source. Keeping the batteries at the bottom not only offers better weight distribution but also helps in managing heat dissipation, which is crucial for maintaining battery health.
4. Ease of Maintenance: The organized layout of the component box simplifies maintenance tasks, allowing users to quickly identify and access specific components as needed. This design reduces the time and effort required for repairs or replacements, promoting a proactive maintenance approach.
5. Durability and Protection: The robust construction of the component box ensures that all housed components are well-protected from physical damage and environmental factors. The insulated shelves contribute to the longevity of the electronics, safeguarding them against wear and tear.

### 3.2.10 The Handle

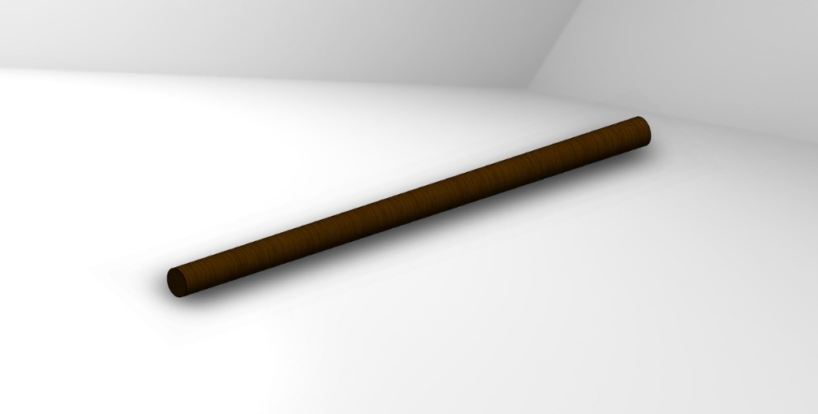
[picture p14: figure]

The handle is an essential feature of our cart, designed with both functionality and user comfort in mind. Its specifications and construction elements play a significant role in ensuring an optimal user experience during operation. It was thoughtfully designed to enhance the user experience by prioritizing comfort, control, and aesthetic appeal. Its dimensions, material choice, and ergonomic design make it a crucial element for effectively driving the cart while ensuring the user's comfort and safety. Figure 3.22, "The Handle of the Cart," provides a detailed view of the handle, highlighting its design and integration into the cart's overall structure.

Figure 3.22 The handle of the cart

- Design Specifications:
1. Dimensions: The handle is designed as a wooden cylinder with a diameter of 20 mm and a length of 400 mm. This size strikes a balance between robustness and ease of grip, making it suitable for various user hand sizes.
2. Material Choice: Crafted from high-quality wood, the handle not only provides a natural aesthetic but also offers a warm and comfortable grip. Wood is known for its durability and strength, ensuring that the handle can withstand continuous use without compromising its integrity.
3. User Comfort: The cylindrical shape and appropriate diameter enhance the comfort of the user while driving the cart. The handle's design allows for a natural hand position, reducing strain during prolonged use. This ergonomic consideration is crucial for minimizing fatigue, especially in scenarios where the cart is operated over extended periods.
4. Grip Texture: The smooth finish of the wooden handle provides a comfortable grip, while the natural texture of the wood helps prevent slipping, even in varying environmental conditions. This feature ensures that users have reliable control over the cart, enhancing safety during operation.
5. Stability and Control: The length of the handle provides adequate leverage, allowing users to maneuver the cart with ease. A longer handle enables better control, especially when navigating tight spaces or making sharp turns.

### 3.2.11 Wheels and couplers

The wheels and couplers are integral components of our cart, designed to ensure smooth mobility and a robust connection to the motor. Their specifications and construction methods contribute significantly to the overall performance and functionality of the cart. Figure 3.23, "The Wheel and the Coupler," illustrates the design and integration of these components, highlighting their role in facilitating seamless movement and efficient power transfer from the motor to the wheels.

Figure 3.23 The Wheel and the Coupler

- Wheel Specifications
1. Diameter and Material: The wheels have a diameter of 13 cm, which strikes an ideal balance between stability and maneuverability. This size allows for smooth movement across various surfaces, making the cart versatile for different operational environments.
2. Design Features: The wheels are designed to provide optimal traction and durability. Their construction materials are selected to withstand wear and tear, ensuring longevity even under continuous use. The tread pattern on the wheels enhances grip, allowing the cart to maintain stability and control during movement.
3. Mobility: The size and design of the wheels facilitate easy navigation, whether on flat surfaces or uneven terrains. This capability is crucial for ensuring that users can operate the cart effectively in diverse settings. Figure 3.24, "The Other Side of the Wheel," offers a view of the wheel's opposite side, showcasing its structural design and material details.

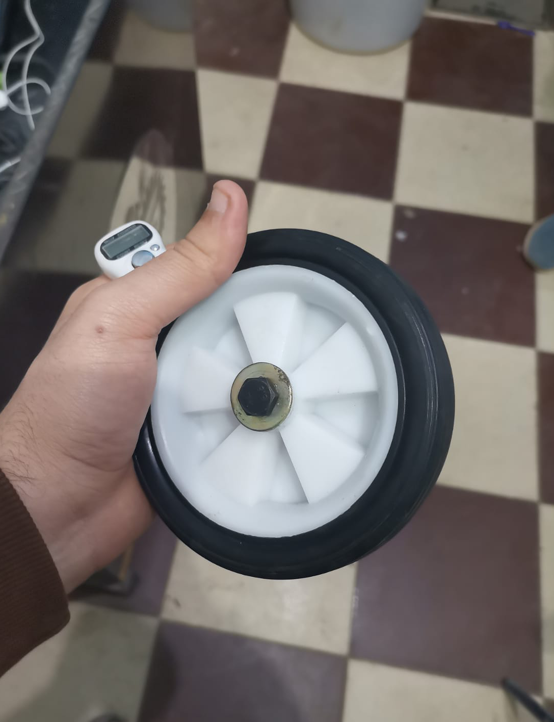
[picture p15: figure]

Figure 3.24 The other side of the wheel

- Coupler Design:
1. Material and Fabrication: The coupler is made of steel, providing superior strength and durability. It is crafted using a lathing machine, which ensures precision in its dimensions and fit. This process allows for a high-quality finish and accurate tolerances, essential for the coupler's functionality.
2. Functionality: The coupler serves as the connection point between the motor shaft and the wheels. It is designed to be securely screwed onto the motor shaft, providing a robust interface that transmits power efficiently. This secure connection is vital for ensuring that the wheels respond properly to the motor's output, enabling smooth operation of the cart.
3. Ease of Installation: The design of the coupler facilitates straightforward installation and maintenance. Users can easily attach or detach the coupler from the motor shaft, allowing for efficient repairs or replacements without significant downtime.
- Overall Integration

The combination of the 13 cm wheels and the steel coupler creates a reliable and efficient system for the cart. The wheels provide the necessary mobility and stability, while the coupler ensures a secure and effective connection to the motor. Together, they enhance the cart’s overall performance, making it a versatile tool for various applications. This thoughtful design approach ensures that users can navigate their environments with confidence and ease, maximizing the cart's utility.

## 3.3 The Difficulties We Faced

### 3.3.1 Mounting the Motor

One of the significant challenges we faced during the mechanical design phase was the precise mounting of the motors. Each motor required a specific design to ensure it was securely fixed in the correct position. This was crucial for maintaining uniformity in the spacing between the wheels and the ground.

The complexity arose from the fact that the fixation points for the motors varied in dimensions, particularly when the assembly was flipped. This inconsistency necessitated meticulous planning and measurement to ensure that all motors were aligned correctly, thereby preventing any discrepancies that could affect the cart's stability and maneuverability.

To overcome these challenges, we implemented a systematic approach to dimensioning the motor fixation points. This involved careful consideration of the angles and distances during the design process, ensuring that each motor was tailored to fit seamlessly within the overall structure.

Our methodology was that we fixed the place of the wheels throughout the design, then from it, we started to add the motors in the assembly one by one, positioning them as they would be in real life so we could determine the exact place for the cut we needed to fix it in position securely on the side of the base.

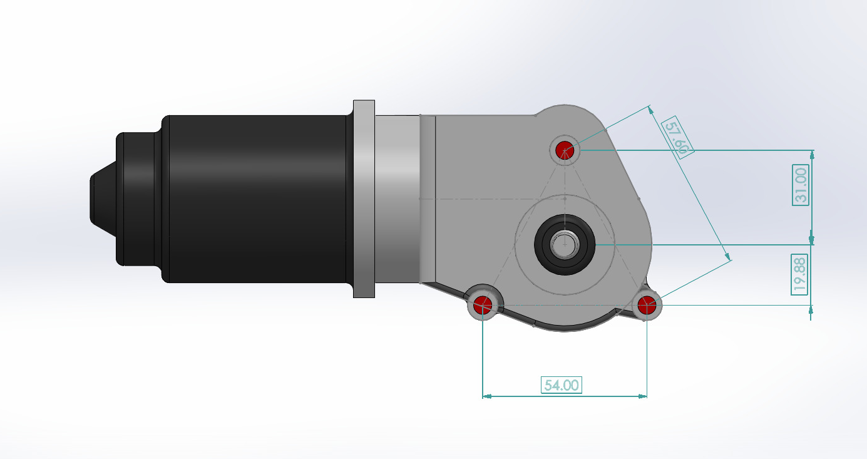
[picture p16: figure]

Through this dedicated effort, we successfully achieved a robust mounting system that not only secured the motors effectively but also contributed to the overall performance and reliability of the cart (Figure 3.25: The dimensions of the motor).

Figure 3.25 The dimensions of the motor

One significant challenge we encountered during the mechanical design phase that was also related to the placement of the motors in relation to the cart's body and wheels was that the designated fastening points for the motors were positioned farther away from the wheel assembly than anticipated. This discrepancy resulted in a noticeable gap between the motors and the cart's body, which posed a risk of instability and misalignment during operation.

To address this issue, we needed to devise a solution that would effectively bridge the distance between the motors and the body. After careful consideration, we opted to incorporate nuts onto the bolts used for fastening the motors. These nuts acted as spacers, allowing us to adjust the height and position of the motors to ensure they were securely fastened and aligned correctly with the wheel assembly.

By using nuts as spacers, we were able to achieve a snug fit that minimized the gap, thereby enhancing the overall stability and functionality of the cart. This solution not only resolved the immediate challenge but also contributed to a more robust design, ensuring that the motors operated efficiently without risking any misalignment during movement.

### 3.3.2 Wiring

Wiring is a critical aspect of our cart’s design, and while we aimed for efficiency and organization, we encountered several challenges during the process. To address these difficulties, we implemented specific design features that facilitated a more streamlined wiring setup (Figure 3.26: Wiring of the lower part).

Figure 3.26 Wiring of the lower part

- Identifying Wiring Challenges:
1. Complex Routing: One of the primary difficulties was the complex routing of wires from the camera, positioned at the highest point of the design, down to the wheels at the bottom. Ensuring that wires were not only connected properly but also neatly arranged to avoid entanglement was a considerable challenge.
2. Limited Space: The confined spaces within the cart made it difficult to maneuver wires without risking damage to other components. This necessitated careful planning to determine optimal pathways for the wiring, ensuring that all connections were secure while avoiding clutter.
3. Accessibility: Ensuring that wires remained accessible for maintenance or troubleshooting was another challenge. Once the cart was assembled, accessing certain wires for adjustments or replacements could become cumbersome.

#### Design Solutions

1. Wiring Guides: To facilitate the wiring process, we created dedicated guides that allowed for the organized passage of wires throughout the cart. These guides helped ensure that wires could be routed efficiently from one component to another, minimizing the risk of tangling or damage.
2. Strategic Cuts: We incorporated several strategically placed cuts in both the upper and lower parts of the cart. These cuts served as designated pathways for the wires, allowing us to thread them securely without compromising the integrity of the design. By providing these openings, we simplified the wiring process, making it easier to pass wires from the camera down to the wheels.
3. Modular Design: The modular nature of the wiring system allowed for easier assembly and disassembly. This design choice made it simpler to make adjustments or repairs without needing to dismantle the entire cart.

Despite the initial challenges, the solutions we implemented ultimately enhanced the overall efficiency of the wiring process. The combination of the wiring guides and strategic cuts allowed for a clean and organized setup, reducing potential issues during operation. Furthermore, these design features have contributed to the cart's reliability, ensuring that all components function harmoniously while remaining accessible for future maintenance. Through careful planning and innovative design, we were able to overcome the difficulties faced during the wiring phase, resulting in a well-structured and user-friendly system.

Chapter 4

Hardware Implementation

# 4. Hardware Implementation

## 4.1 Introduction

The hardware implementation of the "Automated Follow-Me Cart Using AI and Computer Vision" forms the backbone of the project, translating conceptual designs into a functional prototype. This chapter delves into each hardware component’s specifications, selection rationale, integration methodology, and performance considerations. By combining mechanical engineering with advanced electronics, the project achieves a robust and versatile solution tailored for assistive mobility.

## 4.2 Detailed Analysis of Hardware Components

### 4.2.1 Motors

- Type and Specifications:
  - Wiper motors were selected for their proven reliability in automotive applications, ensuring consistent performance under varying loads and environmental conditions.
  - Specifications:
    - Rated Torque: 20 Nm per motor.
    - Maximum Operating Voltage: 12V.
    - Operating Current: 4-5A underload.
    - Motor Efficiency: Approximately 85%.
- Functionality and Role:
  - The motors drive the cart’s wheels, providing smooth and stable movement across various terrains.
  - Designed to handle weights up to 62.7 kg, accommodating the cart’s structure and additional load from user belongings.
- Integration:
  - Mounted on a steel chassis with vibration-damping pads to minimize noise and mechanical wear.
  - Connected to motor drivers through custom-designed couplers for efficient torque transmission.
- Challenges and Solutions:
  - Precise alignment of the motors with the wheel shafts was critical to avoid uneven wear. Custom brackets with adjustable slots were fabricated to ensure perfect alignment.
  - Heat dissipation during extended use was addressed by incorporating passive cooling fins on the motor housing.

### 4.2.2 Motor Drivers

Motor drivers play a crucial role in the Smart Shopping Cart, acting as the intermediary between the microcontroller and the motors, ensuring smooth and efficient operation.

### Functionality

- Speed and Direction Control:
  - The motor drivers enable precise speed and direction control, allowing the cart to execute essential commands such as forward movement, turning, and stopping.
- Pulse Width Modulation (PWM):
  - PWM signals from the Arduino Nano are processed by the motor drivers to achieve accurate control over motor speed and torque, providing responsive and smooth operation.

### Specifications

- Dual-Channel H-Bridge Design:
  - Each driver features a robust H-bridge circuit capable of handling up to 20A per channel, ensuring sufficient power for the cart's motors under various load conditions.
- Current Protection Circuits:
  - Built-in current protection safeguards the motors and electronics from overloads and short circuits, enhancing the system's reliability and longevity.

### Integration

- PCB Mounting:
  - The motor drivers are securely mounted on a custom-designed PCB (Figure 4.1) that includes heat sinks for effective thermal management during extended operations.
- Connection to Arduino Nano:

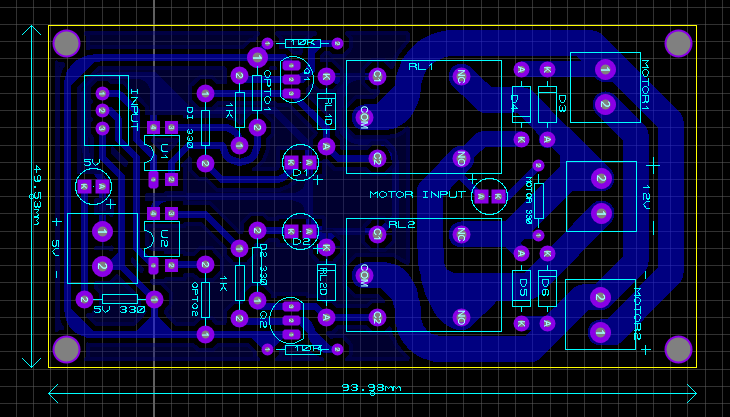
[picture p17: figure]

  - Signal inputs from the Arduino Nano are directly interfaced with the motor driver, ensuring seamless communication.
  - The use of PWM signals provides precision in speed adjustments and smooth transitions between directional changes.

Figure 4.1 Motor Driver Layout

### Visual Representation

- Figure 4.1: Motor driver layout illustrating the dual-channel H-bridge design and integration with cooling mechanisms.
- Figure 4.2: A 3D model of the motor driver, showcasing its compact design and how it integrates with the cart's overall hardware system.
- Figure 4.3: Schematic view of the motor driver circuit, highlighting the connections and functional components.

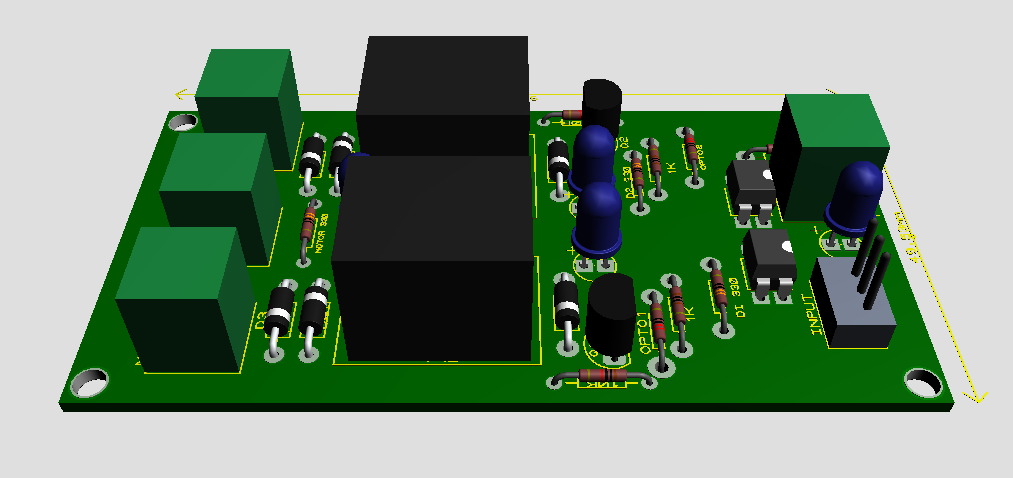
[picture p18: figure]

By employing these motor drivers, the Smart Shopping Cart achieves reliable and responsive movement, ensuring it can perform its tasks efficiently in real-world scenarios. The integration of safety features and precise control mechanisms further enhances the cart's performance and robustness.

Figure 4.2 3d Model for Motor Driver

Figure 4.3 Schematic View for Motor Driver

### 4.2.3 Sensors

Sensors are integral to the Smart Shopping Cart, ensuring accurate obstacle detection and enabling safe navigation. The system incorporates both infrared (IR) and ultrasonic sensors for complementary detection capabilities.

### Infrared (IR) Sensors

- Specifications:
  - Detection Range: 10 cm to 2 m.
  - Operating Voltage: 5V.
  - Response Time: <1 ms.
- Role in the System:
  - IR sensors detect nearby obstacles and provide real-time feedback to the microcontroller. This functionality is critical for navigating crowded or cluttered environments safely.
- Placement:
  - One IR sensor is mounted at the front for forward obstacle detection.
  - Two additional IR sensors are positioned at the sides to enhance peripheral awareness.
- Calibration and Optimization:
  - Thresholds were calibrated during testing to minimize false positives caused by varying lighting conditions.
  - Signal processing algorithms were implemented to filter out noise and improve detection accuracy.
- Illustration:
  - Figure 4.4 shows the layout of an IR sensor used in the system.

Figure 4.4 IR Sensor

### Ultrasonic Sensors

- Specifications:
  - Detection Range: 2 cm to 4 m.
  - Operating Voltage: 5V.
  - Accuracy: ±3 mm.
- Role in the System:
  - Ultrasonic sensors complement IR sensors by providing longer-range obstacle detection. They are especially effective in scenarios where lighting conditions may impact IR sensor performance.
  - These sensors ensure precise distance measurement and help in detecting obstacles at varying heights.
- Placement:
  - Ultrasonic sensors are mounted at the front and rear of the cart to provide 360-degree coverage for obstacle detection and collision prevention.
- Calibration and Optimization:
  - The sensors were tuned for maximum sensitivity and accuracy during testing.
  - Advanced filtering techniques were used to eliminate false readings caused by sound reflection from nearby objects.
- Illustration:
  - Figure 4.5 shows the layout of an Ultrasonic sensor used in the system.

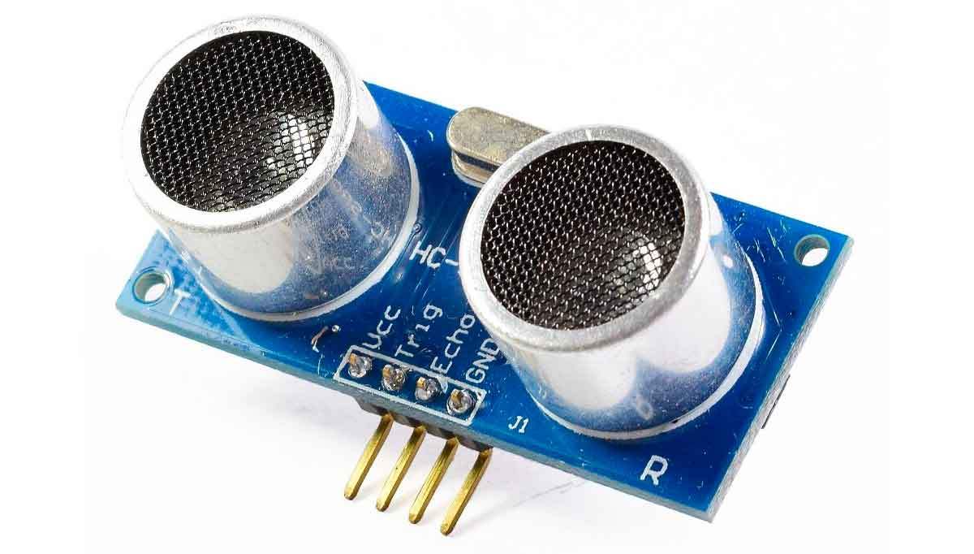
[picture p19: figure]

Figure 4.5 Ultrasonic Sensor

### 4.2.4 Camera

• Specifications:

  - Resolution: 1920 x 1080 pixels.
  - Frame Rate: 30 fps.
  - Field of View: 120 degrees.

• Functionality:

  - Captures real-time video for gesture recognition and user tracking.

• Integration:

  - Directly interfaced with the NVIDIA Jetson platform via a USB 3.0 connection to leverage high-speed data transfer.
  - Mounted on an adjustable bracket to ensure optimal viewing angle.

• Illustration:

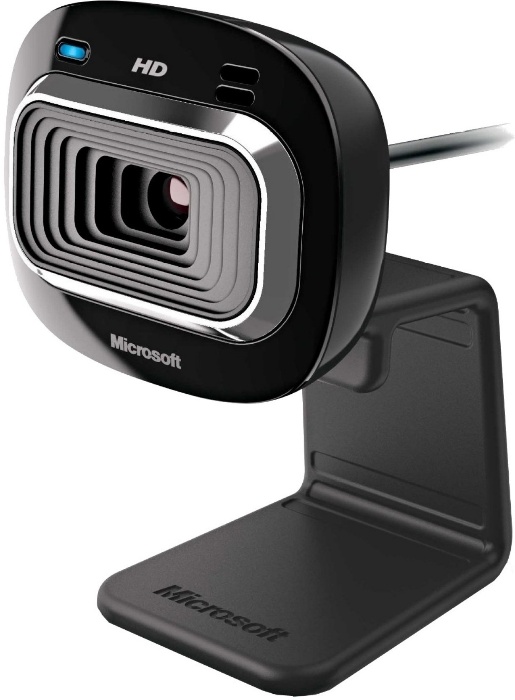
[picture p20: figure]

  - Figure 4.6 shows the camera used in conjunction with the Jetson Nano platform.

Figure 4.6 Camera used with Jetson Nano

### 4.2.5 Microcontroller (Arduino Nano)

- Specifications:
  - Processor: ATmega328P.
  - Operating Voltage: 5V.
  - Digital I/O Pins: 14.
- Role:
  - The Arduino Nano manages auxiliary functions, such as motor speed adjustments and sensor data acquisition.
- Integration:
  - Communicates with the NVIDIA Jetson platform over UART for seamless operation.
  - Powered through a dedicated 5V rail on the power distribution board to ensure stable performance.

Figure 4.7 shows the Arduino Nano used in the project, illustrating its compact and versatile design.

Figure 4.7 Arduino Nano

### 4.2.6 NVIDIA Jetson Platform

- Specifications:
  - GPU: 128-core Maxwell architecture.
  - Memory: 4GB LPDDR4.
  - Interfaces: CSI camera, USB 3.0, GPIO.
- Functionality:
  - Processes camera input for real-time hand gesture recognition.
  - Executes AI algorithms for obstacle avoidance and user following.
- Integration:
  - Installed on a vibration-dampened mount to ensure stability during operation.
  - Paired with a cooling fan to maintain optimal operating temperatures.

Figure 4.8 illustrates the Jetson Nano used in the project, showcasing its compact yet powerful design tailored for AI and robotics applications.

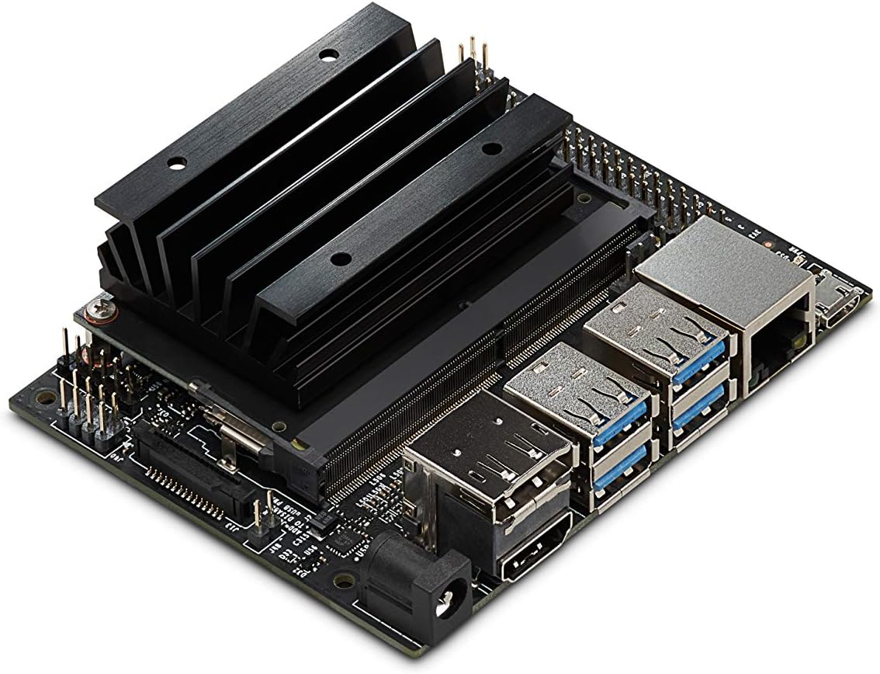
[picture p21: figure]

Figure 4.8 Jetson Nano

### 4.2.7 Battery

- Specifications:
  - Type: Lithium-ion.
  - Model: Royal Battery 12n9-bs.
  - Capacity: 12V, 32Ah.
- Power Management:
  - Provides power to the motors, microcontroller, sensors, and Jetson platform.
  - Includes a Battery Management System (BMS) for overcharge and over-discharge protection.
- Figure 4.9: Royal Battery 12N9-BS, used as the primary power source for the system.

Figure 4.9 Royal Battery 12N9-BS

### 4.2.8 Mechanical Components

- Materials:
  - Sheet metal for the chassis to ensure durability.
  - Wood for housing electronic components, providing insulation and lightweight.
- Design Considerations:
  - The chassis was analyzed using finite element analysis (FEA) to optimize weight distribution and stress tolerance.

## 4.3 Integration and Implementation

### 4.3.1 Wiring and Assembly

- All wiring harnesses were organized using cable management channels.

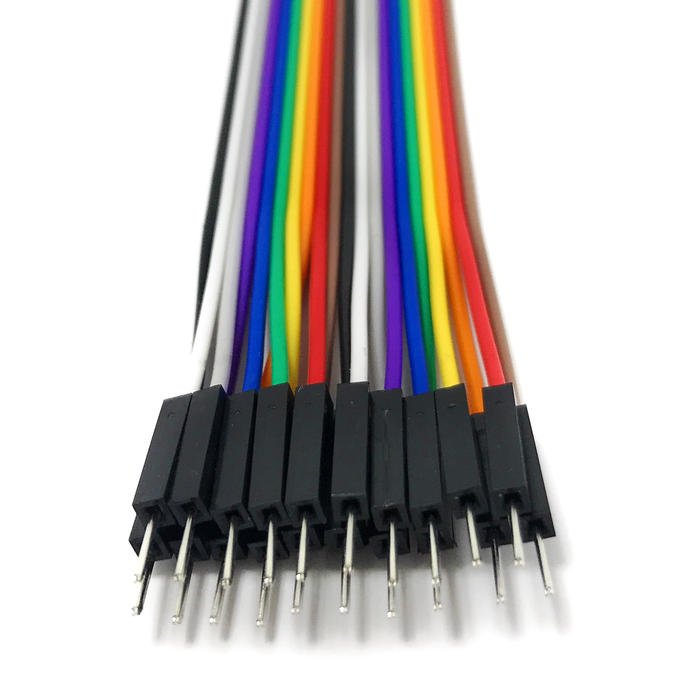
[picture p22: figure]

- Color-coded wires were used to simplify troubleshooting and maintenance (see Figure 4.10: Jumpers and Wires).

Figure 4.10 Jumpers

4.3.2 PCB Design and Layout
The Smart Shopping Cart relies on three custom-designed PCBs to ensure smooth functionality, safety, and user control. Each PCB serves a specific purpose within the system and has been designed with precision to minimize interference, improve reliability, and ensure ease of maintenance. This section breaks down the design, layout, and integration of each PCB, including the Motor Driver PCB, Safety PCB, and Joystick PCB.

### 1. Motor Driver PCB

The Motor Driver PCB is responsible for controlling the motors of the Smart Shopping Cart, acting as the interface between the microcontroller (Arduino Nano) and the motors. This board ensures that the cart’s motors operate efficiently, responding to commands such as forward movement, turning, and stopping. The motor drivers utilize Pulse Width Modulation (PWM) signals from the microcontroller, converting them into appropriate motor speed and torque adjustments.

The Motor Driver PCB features several key components designed to handle high current loads, including H-bridge circuits for motor control and built-in protection circuits to safeguard against overloads. To prevent overheating during continuous operation, the PCB includes heat sinks integrated into its layout for effective thermal management.

- Figure 4.1: Layout of the Motor Driver PCB, highlighting the components and their connections, including thermal management features such as heat sinks.
- Figure 4.3: Schematic view of the Motor Driver PCB, detailing the electrical connections for motor control and safety mechanisms.

By ensuring reliable motor control through this PCB, the Smart Shopping Cart can move accurately and respond to user commands without delay.

### 2. Safety PCB

The Safety PCB is designed to ensure the protection of the cart’s sensitive electronics and components from electrical issues, such as overcurrent, overheating, and short circuits. This board integrates several safety features, including overcurrent protection circuits, thermal shutdown mechanisms, and fail-safe systems that automatically disconnect power in case of a fault.

One key design feature of the Safety PCB is its fault tolerance, achieved through redundant power paths that ensure continued operation if one path fails. This redundancy helps maintain the cart’s safety in case of component failure, providing extra reliability in critical situations.

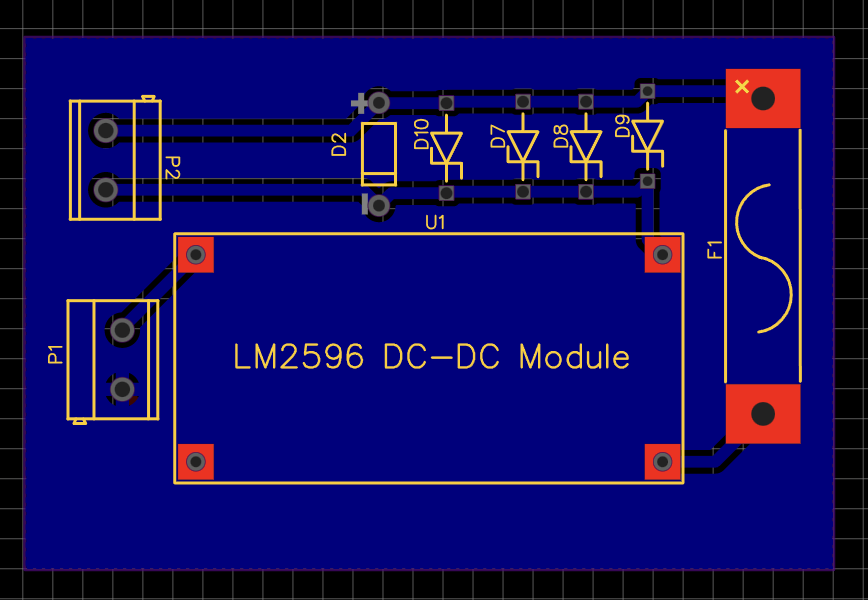
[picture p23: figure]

- Figure 4.11: Layout of the Safety PCB, showcasing the placement of protective components, such as current sensors and thermal protectors, as well as the redundant power paths incorporated into the design.

Figure 4.11 Safety PCB Layout

- Figure 4.12: 3D view of the Safety PCB, emphasizing its compact form factor and the strategic positioning of thermal management components. This figure highlights how the board integrates with the overall system.

Figure 4.12 3d Model for Safety PCB

- Figure 4.13: Schematic view of the Safety PCB, illustrating the electrical connections between safety features like current protection and temperature sensors. This schematic also outlines the flow of power through the redundant paths to ensure fault tolerance.

By including these safety features, the Safety PCB helps protect the cart’s components from damage and ensures the system operates reliably under varying conditions.

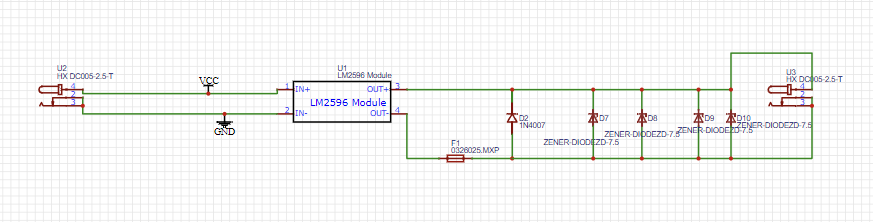
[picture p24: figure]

Figure 4.13 Schematic View for Safety PCB

### 3. Joystick PCB

The Joystick PCB is crucial for user interaction with the Smart Shopping Cart. This board translates the user's joystick movements into electrical signals, which are then interpreted by the microcontroller to control the cart’s movement. The design of the Joystick PCB focuses on low latency and high responsiveness, ensuring that user inputs are translated quickly and accurately into cart motions.

The Joystick PCB includes an analog-to-digital converter (ADC) to process the analog joystick signals into digital values that can be read by the microcontroller. Additionally, it features organized wiring and components for efficient signal routing to minimize interference and ensure smooth operation.

- Figure 4.14: Layout of the Joystick PCB, showing the organization of components such as the joystick interface and ADC converter, and highlighting how the layout contributes to the board’s responsiveness.

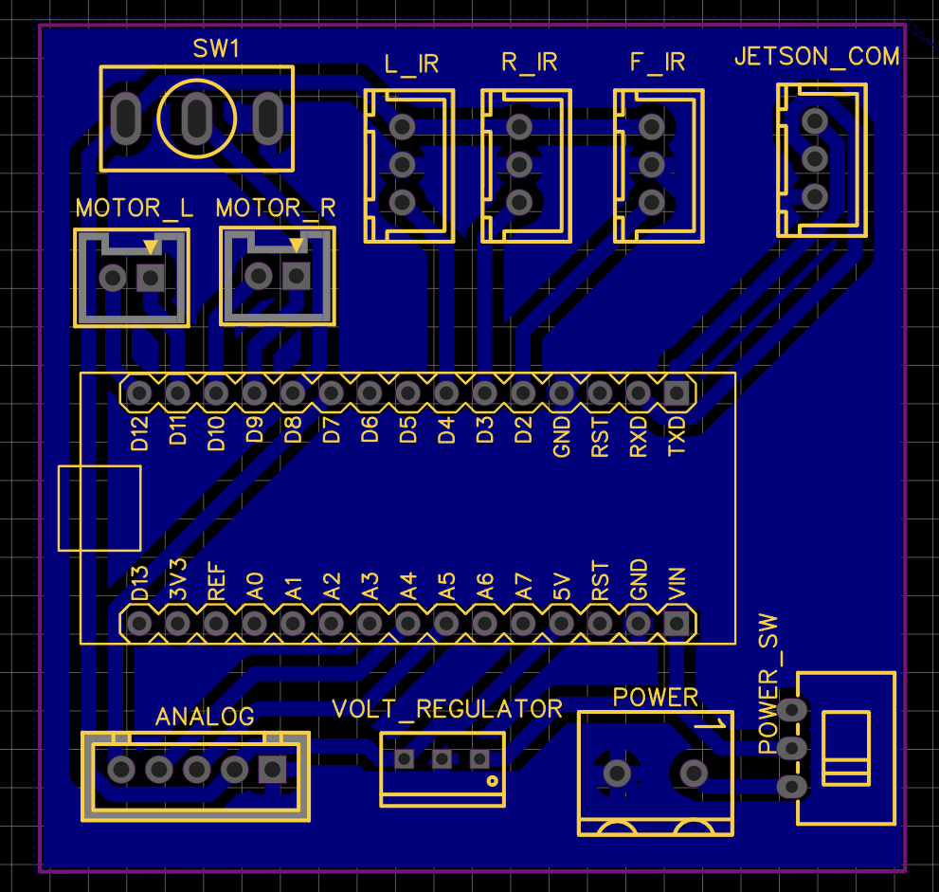
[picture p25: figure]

Figure 4.14 Joystick PCB Layout

Figure 4.15: 3D view of the Joystick PCB, illustrating how the board integrates into the Smart Shopping Cart’s user interface, with attention to its compact design and functional placement.

Figure 4.15 3d Model for Joystick PCB

Figure 4.16: Schematic view of the Joystick PCB, showing the electrical pathways from the joystick to the microcontroller, including the signal processing circuit and ADC conversion process.

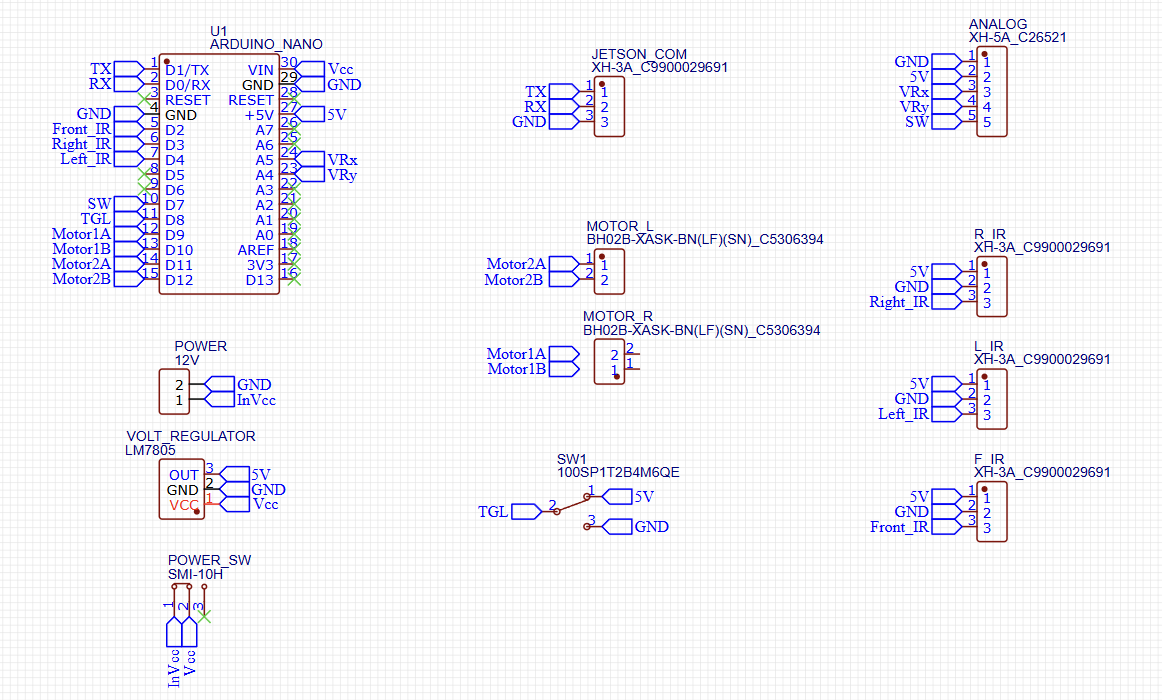
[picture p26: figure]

With this PCB, users can easily control the cart’s movement through intuitive joystick inputs, enhancing the cart's usability and responsiveness.

Figure 4.16 Schematic View for Joystick PCB

### PCB Design Conclusion

The three custom PCBs—Motor Driver PCB, Safety PCB, and Joystick PCB—form the backbone of the Smart Shopping Cart’s electronic system, each contributing to a specific function that enhances overall performance, safety, and user interaction. By employing these PCBs, the cart achieves reliable movement control, effective protection from electrical hazards, and seamless user input response. The integration of fault tolerance and precise layouts further boosts the cart’s robustness, ensuring it operates effectively in real-world environments.

### 4.3.3 Challenges and Solutions

The design and development of the Smart Shopping Cart presented several technical challenges, primarily related to the integration of electronic components and ensuring that the cart would function effectively in real-world conditions. Below are some of the key challenges encountered during the design process and the corresponding solutions that were implemented:

#### Space Constraints for Mounting Electronic Components

One of the most significant challenges was the limited space available for mounting the various electronic components within the Smart Shopping Cart’s compact structure. The cart needed to accommodate several PCBs, sensors, motors, wiring, and safety features, all while maintaining an ergonomic and user-friendly design.

- Solution:

To overcome the space limitations, multi-layered mounting brackets were designed. These custom-designed brackets allow for efficient use of available space by stacking components vertically, rather than arranging them on a single plane. This solution not only maximized the use of the cart’s internal space but also ensured that each component was securely fixed in place, minimizing the risk of components shifting or becoming loose during operation. Additionally, these mounting brackets were designed to be modular, allowing for easy assembly and disassembly for maintenance or upgrades.

#### Heat Management for Electronics

Another challenge involved managing the heat generated by electronic components, especially the motor drivers and power supply circuits. Continuous operation of the motors would generate significant heat, which could potentially damage sensitive components if not properly dissipated.

- Solution:

The inclusion of integrated heat sinks on the Motor Driver PCB and careful design of the Safety PCB helped manage thermal buildup. The heat sinks were strategically positioned to ensure that heat was effectively drawn away from high-temperature components, such as the motor drivers. Additionally, passive cooling methods were used to reduce the need for active cooling fans, making the cart quieter and more energy-efficient.

#### Wiring and Signal Interference

Signal interference between various components, particularly in the wiring for motors and sensors, presented a significant challenge. The complexity of the system required clear and interference-free signals to ensure smooth operation, particularly for sensitive components like the sensors and joystick.

- Solution:

To combat interference, careful attention was given to the routing of wires and cables. Shielded cables were used in critical signal paths to protect them from electromagnetic interference. Furthermore, the layout of the PCB and the physical placement of wires were optimized to ensure that power lines and signal lines were kept separate as much as possible. Additionally, cable management channels were incorporated into the design to keep wiring organized, preventing tangling and reducing the risk of signal interference.

#### Ensuring Structural Integrity While Reducing Weight

The design of the Smart Shopping Cart needed to balance the structural integrity of the frame with the goal of keeping the overall weight as low as possible. Excessive weight would negatively impact the cart’s movement and efficiency, while insufficient structural strength could result in failure or instability during operation.

- Solution:

To achieve this balance, lightweight yet durable materials, such as high-strength plastic composites and aluminum alloys, were chosen for the cart’s frame. The structural design was optimized using SolidWorks, employing advanced modeling techniques such as Finite Element Analysis (FEA) to identify weak points and ensure maximum strength without adding unnecessary weight. The use of multi-layered mounting brackets also helped distribute the weight evenly, preventing strain on any single component.

By addressing these challenges through thoughtful design, material selection, and engineering solutions, the development of the Smart Shopping Cart progressed smoothly, ensuring it could operate reliably and efficiently under a variety of conditions.

### 4.3.4 Testing and Validation

Once the design and assembly of the Smart Shopping Cart were completed, the next critical phase was testing and validation. This stage was essential to ensure that the cart performed reliably, safely, and efficiently in real-world conditions. A comprehensive set of tests was conducted to validate various aspects of the system, from motor performance to sensor reliability.

#### Load Tests to Evaluate Motor Performance

To ensure that the motors used in the Smart Shopping Cart were capable of handling varying load conditions without loss of performance or overheating, a series of load tests were conducted. These tests involved simulating different payloads that the cart might carry in everyday use, ranging from light to heavy loads.

  - Test Process:

The motors were tested by gradually increasing the load they were required to move, monitoring the motor speed, torque, and temperature at each stage. Special attention was given to ensure that the motor drivers and the motors themselves remained within their operational limits under load. The PWM control signals from the Arduino Nano were adjusted to monitor how effectively the motor speed could be controlled under varying loads, ensuring smooth movement without stalling or excessive strain.

- Findings and Adjustments:

During initial testing, slight variations in motor performance were observed under heavy load conditions, particularly with regard to speed consistency. As a result, adjustments were made to the motor driver configuration, including fine-tuning the PWM signal parameters to provide more precise motor control under load. Additionally, the heat sinks on the motor driver PCB were optimized to ensure that thermal buildup did not compromise motor performance.

#### Environmental Tests to Ensure Sensor Reliability

The reliability of the sensors, particularly the proximity and obstacle detection sensors, was tested under various environmental conditions. This was crucial to ensure that the cart could operate in a wide range of real-world scenarios, including different lighting conditions and varying environmental factors, such as shadows and reflections.

  - Test Process:

The sensor reliability tests involved exposing the cart to different environments, including bright sunlight, low-light conditions, and artificial lighting, to simulate real-world shopping environments. The sensor response times and accuracy were closely monitored during each test, with particular focus on how well the cart’s sensors detected obstacles in different lighting conditions. Environmental variables such as temperature and humidity were also monitored to determine if these factors had any adverse effects on sensor performance.

- Findings and Adjustments:

During the testing, it was found that certain sensors exhibited reduced accuracy under low-light conditions, particularly the infrared sensors used for obstacle detection. To address this issue, the sensor calibration algorithms were adjusted, and additional sensors were integrated to improve the cart's detection accuracy in low-light or fluctuating lighting conditions. Furthermore, the sensors’ housings were modified to reduce sensitivity to external factors, ensuring consistent performance in a variety of environments.

#### Battery and Power Efficiency Tests

Another critical aspect tested was the battery life and power efficiency of the Smart Shopping Cart. Since the cart is designed for continuous movement and interaction, it was essential to ensure that the battery could support extended usage without frequent recharging.

  - Test Process:

The battery tests involved measuring the power consumption of the cart during normal operation, including during idle time and while performing different tasks such as moving and turning. The battery voltage, current draw, and overall efficiency were monitored over an extended period of time to determine the cart’s operational range.

- Findings and Adjustments:

Initial tests showed that the cart consumed more power than expected under continuous load. As a result, the power management system was refined, and the battery capacity was upgraded to ensure that the cart could operate for longer periods without a recharge. Additionally, the energy-efficient motor drivers were further optimized to reduce power loss during movement.

#### User Experience and Safety Tests

Finally, user experience testing was conducted to ensure that the Smart Shopping Cart was intuitive and easy to use for shoppers, especially those with disabilities or elderly users who may require additional assistance.

  - Test Process:

A group of test users was selected to interact with the cart, providing feedback on the usability of the joystick interface, responsiveness of the motor controls, and overall ease of navigation. Special attention was paid to the safety features, such as automatic braking in case of a collision or obstacle detection failure. Feedback was gathered to refine the cart’s user interface and ensure that it met accessibility standards.

- Findings and Adjustments:

User feedback led to several key changes, including adjustments to the joystick sensitivity to improve control accuracy and the addition of extra safety features, such as automatic stopping when the cart nears obstacles. Additionally, the cart’s instructions were simplified to ensure that elderly or disabled users could quickly understand how to operate the cart.

## 4.4 Hardware Optimization

### 4.4.1 Energy Efficiency

- Sleep Modes:
  - The Arduino Nano and Jetson platform were programmed to enter low-power sleep modes during idle periods, reducing energy consumption.
  - Sensors and peripherals were also put into standby mode when not actively used, ensuring minimal power draw.
- Power Regulation:
  - A high-efficiency DC-DC converter was utilized to regulate power distribution and minimize energy loss.
  - Separate voltage rails were implemented to optimize power delivery to components, reducing unnecessary energy waste.
- Battery Monitoring:
  - Integrated a real-time battery monitoring system to track power usage and provide early warnings for low battery levels, enabling better energy management.
  - The Battery Management System (BMS) also ensures optimized charging cycles, prolonging the battery lifespan.
- Energy-Efficient Algorithms:
  - Computational tasks on the Jetson platform were optimized by employing lightweight YOLO models (e.g., YOLOv8 Nano) and Mediapipe modules, reducing the system's overall power requirements.

### 4.4.2 Durability Enhancements

- Structural Reinforcement:
  - Critical joints were reinforced with high-strength bolts, reducing the risk of failure under load or vibration.
  - Welds were inspected and tested for uniformity to ensure structural integrity during operation.
- Protective Covering:
  - A protective acrylic enclosure was installed over the electronics to safeguard against dust, moisture, and accidental impacts.
  - The acrylic cover included ventilation slots to prevent overheating while maintaining protection.
- Cable Management:
  - All wiring harnesses were organized using cable management channels to prevent tangling and ensure ease of maintenance.
  - Heat-resistant cable sleeves were added to protect wires from potential thermal damage near the motors and power components.
- Vibration Dampening:
  - Rubber mounts and vibration-dampening materials were used under the motor mounts and the Jetson Nano platform, reducing the impact of vibrations on sensitive components.
- Environmental Protection:
  - Components were treated with corrosion-resistant coatings to enhance durability in humid or dusty environments.
  - The motor drivers and PCBs were coated with a conformal layer to protect against moisture and potential short circuits.

### 4.4.3 Thermal Management

- Cooling System:
  - A high-speed cooling fan was installed on the Jetson Nano, and heatsinks were added to the motor drivers to ensure components operate within optimal temperature ranges.
  - Airflow pathways were designed for maximum cooling efficiency, preventing thermal throttling during prolonged use.
- Thermal Sensors:
  - Temperature sensors were integrated near critical components to monitor real-time thermal conditions.
  - The system was programmed to trigger a safe shutdown or reduce processing loads in case of overheating.

### 4.4.4 Maintenance Considerations

- Modular Design:
  - Components were mounted on modular brackets, allowing for quick replacement or upgrades without requiring extensive disassembly.
  - A detailed wiring diagram and component map were created for troubleshooting and repairs.
- Service Indicators:
  - LEDs were installed to indicate system health, including power status, connectivity, and errors, simplifying diagnostics.

## 4.5 Challenges and Lessons Learned

### 4.5.1 Key Difficulties

- Subsystem Integration:
  - Maintaining seamless communication between multiple subsystems (Jetson Nano, Arduino Nano, sensors, and motor drivers) posed significant challenges.
  - Differences in communication protocols (UART, PWM, and GPIO) required meticulous configuration and debugging to ensure compatibility and reliability.
  - Synchronizing real-time data processing, such as hand gesture recognition and obstacle detection, demanded rigorous testing to eliminate latency and data loss.
- Thermal Management:
  - Ensuring efficient heat dissipation for high-power components like the Jetson Nano and motor drivers within a compact design was particularly challenging.
  - Limited space for airflow and the need for additional components (e.g., cooling fans and heatsinks) required iterative redesigns to achieve optimal thermal management without compromising system performance.
- Power Consumption:
  - Balancing the power requirements of high-performance components with the battery’s capacity was a critical issue.
  - Achieving energy efficiency without sacrificing functionality, particularly during prolonged operations, involved extensive testing and optimization of hardware and software.
- Obstacle Detection and Avoidance:
  - Ensuring accurate obstacle detection using IR and ultrasonic sensors proved difficult in varying environmental conditions such as bright lighting, reflective surfaces, and cluttered spaces.
  - Fine-tuning sensor thresholds and implementing robust signal filtering algorithms required several iterations.
- Mechanical Durability:
  - Designing a structure capable of withstanding vibrations and impacts during operation while maintaining lightweight construction was a significant challenge.
  - Material selection and joint reinforcement required careful consideration to achieve both durability and mobility.
- Prototyping and Testing:
  - Initial prototypes revealed unforeseen issues, such as wiring failures, inconsistent sensor readings, and poor mounting stability, necessitating frequent redesigns.
  - Debugging software and hardware simultaneously while integrating new features was time-consuming and required effective team coordination.

### 4.5.2 Lessons Learned

- Importance of Modular Design:
  - Adopting a modular approach in hardware and software development simplified iterative improvements and troubleshooting.
  - Modular components allowed for easy replacement, upgrades, and debugging, reducing downtime during testing phases.
- Value of Early Prototyping:
  - Early prototyping highlighted potential integration issues, such as signal interference and structural weaknesses, enabling the team to address these challenges before final implementation.
  - Prototypes also provided valuable insights into user interaction and system performance, guiding subsequent design improvements.
- Thorough Testing Is Crucial:
  - Rigorous testing under different environmental conditions (e.g., lighting, terrain, and obstacle configurations) was essential to identify and mitigate edge cases that could compromise system reliability.
  - Testing also helped refine calibration parameters for sensors and motors, improving overall system accuracy and responsiveness.
- Team Coordination and Communication:
  - Effective collaboration between team members across various domains (mechanical, electrical, and software) was critical in overcoming integration challenges.
  - Regular meetings and documentation ensured that all team members were aligned on project goals and progress.
- Flexibility in Problem-Solving:
  - Encountering unexpected issues required the team to adopt creative solutions, such as using alternative materials, redesigning components, or refining software algorithms.
  - Learning to adapt quickly to changing requirements and constraints was a valuable skill gained during the project.
- Energy Efficiency as a Priority:
  - Balancing performance and energy consumption required significant effort but emphasized the importance of optimizing algorithms and power management systems.
  - This experience underscored the need to consider energy efficiency from the initial stages of design.
- Documentation and Planning:
  - Maintaining detailed documentation throughout the project streamlined troubleshooting and ensured continuity when handing over tasks between team members.
  - Proper planning and task allocation helped prevent delays and ensured efficient use of available resources.

### Conclusion

The hardware implementation of the Automated Follow-Me Cart was a meticulously designed and integrated system that brought together mechanical durability, electronic precision, and energy efficiency to meet the needs of its intended users. The careful selection of components such as the NVIDIA Jetson Nano, Arduino Nano, IR and ultrasonic sensors, and robust motor drivers ensured seamless communication and reliable performance. Through extensive testing and optimization, the team achieved a design that balances functionality, scalability, and energy conservation.

The integration of a modular approach allowed for adaptability, while the emphasis on durability and efficient power management enhanced the system's long-term reliability. Each component, from the reinforced mechanical structure to the advanced computing and sensing systems, worked cohesively to deliver a practical solution for assisting elderly and disabled individuals. This hardware foundation not only fulfilled the project objectives but also paved the way for future enhancements, underscoring the importance of innovation, teamwork, and iterative design in engineering complex systems.

Chapter 5

Software Integration

# 5. Software Integration

## 5.1 Software and System Integration Introduction

In today’s fast-paced world, automation and convenience are transforming the retail experience. This project introduces a Smart Shopping Cart that integrates advanced computer vision and machine learning technologies to enhance customer convenience. This document delves into the software architecture and system design that make the project feasible, focusing on the integration of Jetson Nano, ATmega328P, and various sensors.

## 5.2 Why Smart Shopping Cart

The concept of a Smart Shopping Cart addresses several critical challenges in modern retail and offers significant benefits across various domains:

  1. Enhancing Customer Convenience
- Time Efficiency: Customers no longer need to manually push carts or stand in long queues. The cart tracks them and automates checkout, streamlining the shopping experience.
- Accessibility: Assists individuals with mobility challenges by offering automated navigation and gesture-based controls.
  2. Retail Innovation
- Competitive Edge: Retailers adopting smart carts can differentiate themselves in a crowded market, attracting tech-savvy customers.
- Data-Driven Insights: The system can collect anonymous shopping patterns to help businesses optimize inventory and layout.
  3. Integration with Smart Ecosystems
- Seamless Technology: Combines IoT, machine learning, and automation to fit into a future of interconnected smart devices.
- Scalability: Can evolve to incorporate additional features like personalized promotions, voice recognition, and payment integration.
  4. Addressing Labor Shortages
- Automated solutions like the Smart Shopping Cart can reduce the dependency on staff for tasks like stocking assistance or customer support, addressing labor gaps without compromising service quality.
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

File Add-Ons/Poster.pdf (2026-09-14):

## Key Features of the Cart


# App

# Battery Monitoring

Track battery status anytime

# Store Mapping

Navigate with real-time mapping

# Item Tracking

Navigate with real-time mapping

# Remote Control

Move the cart effortlessly via the app.

## AI-Powered Gesture Recognition

Hands-free, intuitive control.

Real-time safety for smooth navigation.

## Obstacle Detection & Avoidance

Enhances mobility and independence.

## Autonomous User Following

Designed for various terrains with extended usability.

## Durable & Portable

# Stay Close, Move Freely

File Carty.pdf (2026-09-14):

## Project Overview

### The Automated Follow-Me Cart combines AI and computer vision to assist elderly and disabled individuals

with hands-free mobility. It autonomously follows users, avoids obstacles, and recognizes gestures.

### Paired with a mobile app, it offers features like battery monitoring, store navigation, item tracking, and remote

control, ensuring convenience and full user control.

### Designed for various environments, the cart promotes

independence and inclusivity through innovative technology.

## Project Goal

Enhancing Independence and Convenience

To create a smart, hands-free mobility solution that increases independence, safety, and ease of use in daily activities.

## The automated

Follow me cart solution

An intelligent cart with automated motion, gesture-based control, and mobile app feedback to ensure a seamless and user-friendly experience.

Solution

## User end Features

A Comprehensive system

Allows users to operate the cart manually when needed.

Manual Control Section

Utilizes a camera for automated motion, following the user seamlessly.

Autonomous Navigation Section

Provides real-time monitoring and control via a mobile app.

Feedback and Monitoring Section

### APP

UI

User interface

### Follow-Me Carty App! Empowering your mobility with AI and seamless control

### APP

UI

User interface

How

Works

1. Register
2. Recognition

Control

Navigation


Cart Content

Battery

## Key Sections

Of the Project
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

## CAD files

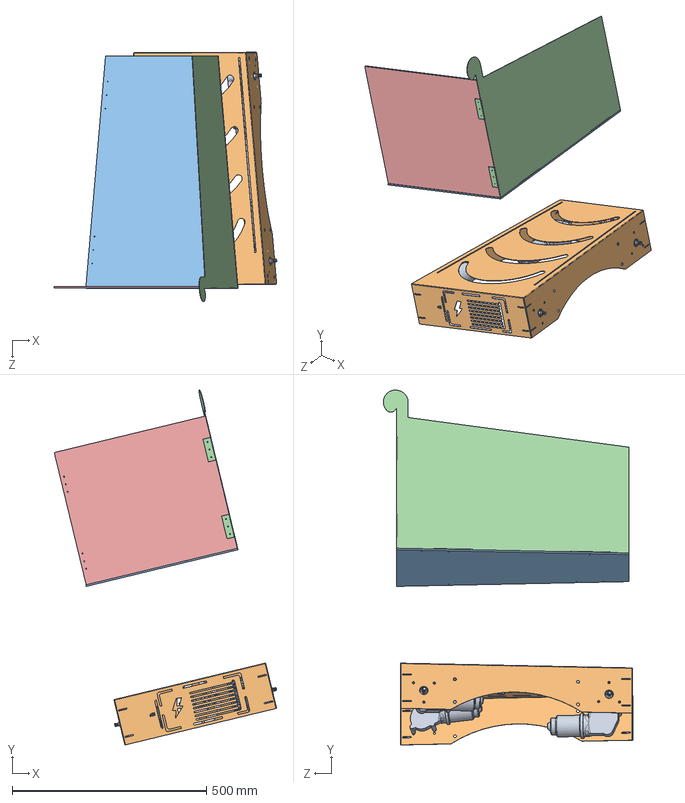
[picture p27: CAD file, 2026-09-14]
Solidworks_Design/Graduation Project 2 n/Graduation Project 2/assembly final project.SLDASM
572.5 x 913.3 x 641.7 mm
back follow
R. side follow
Base Follow
Base Base Follow
Motor 100rpmn1 x 4

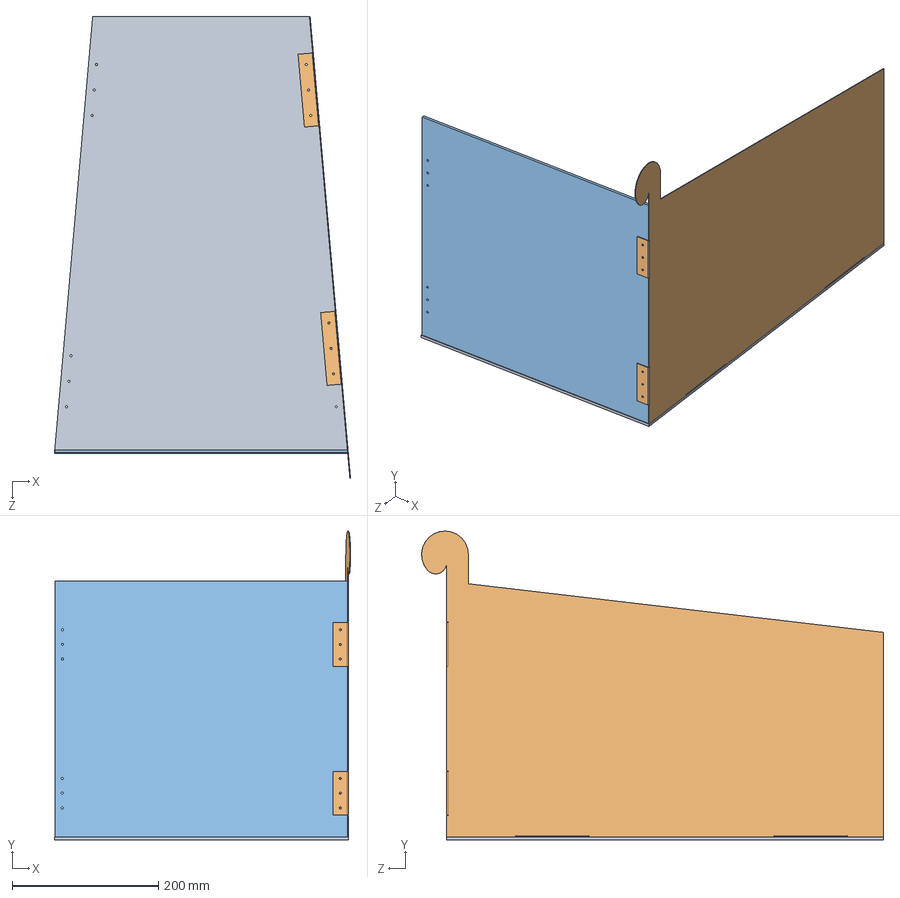
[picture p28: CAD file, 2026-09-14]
Solidworks_Design/Graduation Project 2/assembly final project.SLDASM
405.2 x 422.7 x 632.1 mm
back follow
R. side follow
Base Follow

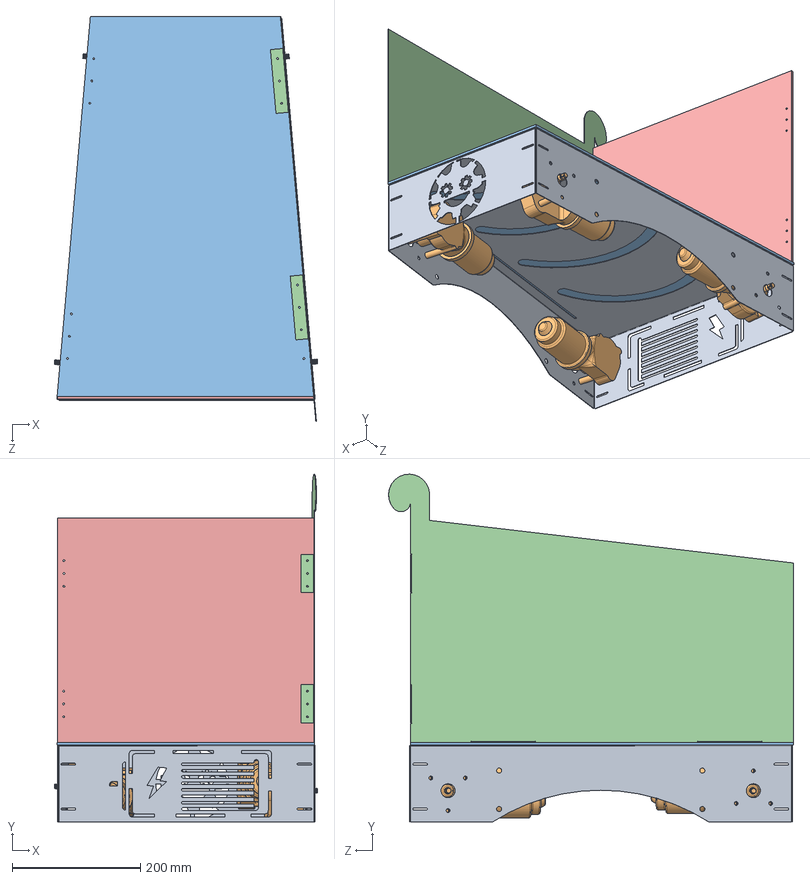
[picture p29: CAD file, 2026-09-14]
Solidworks_Design/Graduation Project 2 n/Graduation Project 2/Assem1.SLDASM
410.9 x 542.7 x 632.1 mm
back follow
R. side follow
Base Follow
Motor 100rpmn1 x 4
Base Base Follow

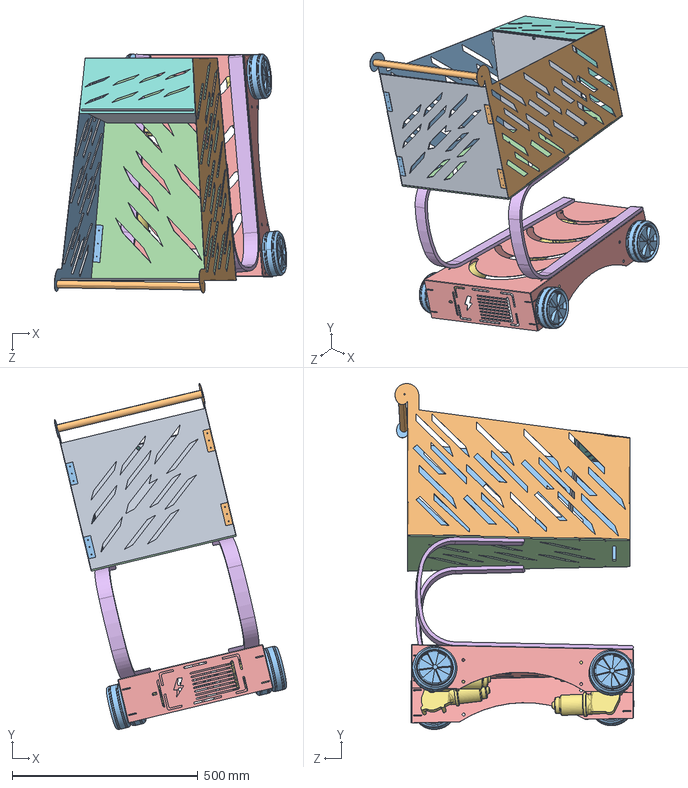
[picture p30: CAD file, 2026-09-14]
Solidworks_Design/Graduation Project 2 (LAST)/assembly final project.STEP
625.4 x 931.2 x 643.5 mm
back follow
R. side follow
L. Side Follow
Base Follow
Base Base Follow
curve x 2
Motor 100rpmn1 x 4
Closing Box
holding hand
wheels x 4

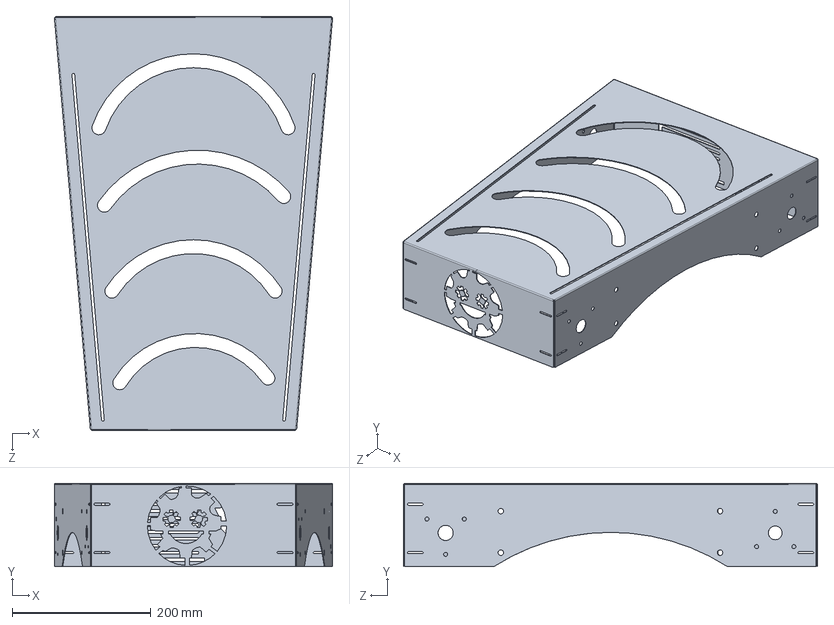
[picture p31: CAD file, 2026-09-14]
Solidworks_Design/Graduation Project 2 (LAST)/Base Base Follow.SLDPRT
401.9 x 120.0 x 597.7 mm

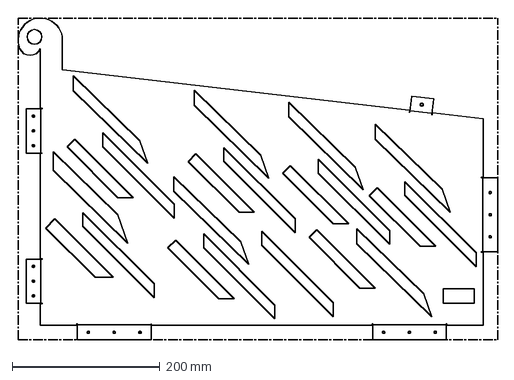
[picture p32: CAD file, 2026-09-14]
Solidworks_Design/Graduation Project 2 n/DXF/L. Side Follow.DXF
651.8 x 438.2 mm

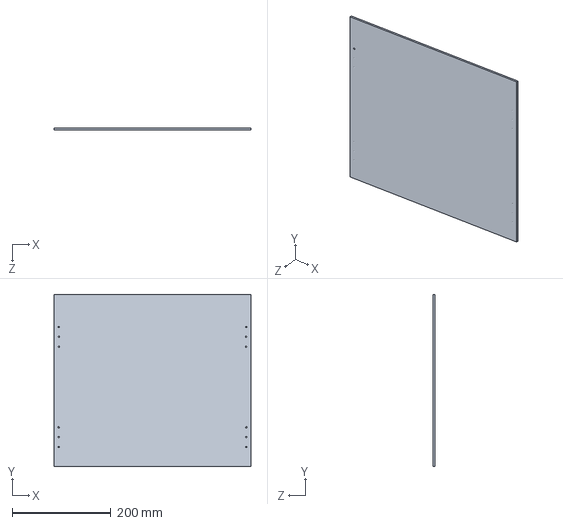
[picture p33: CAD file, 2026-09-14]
Solidworks_Design/Graduation Project 2/back follow.SLDPRT
400.0 x 350.0 x 4.00 mm

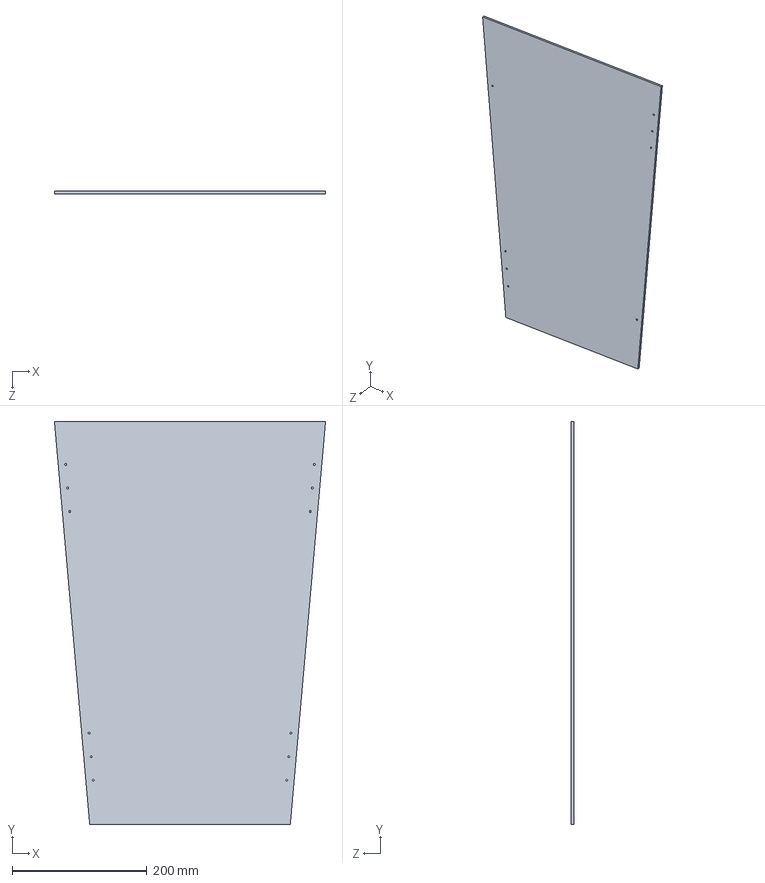
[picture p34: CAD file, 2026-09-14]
Solidworks_Design/Graduation Project/Base Follow.SLDPRT
402.2 x 597.7 x 4.00 mm

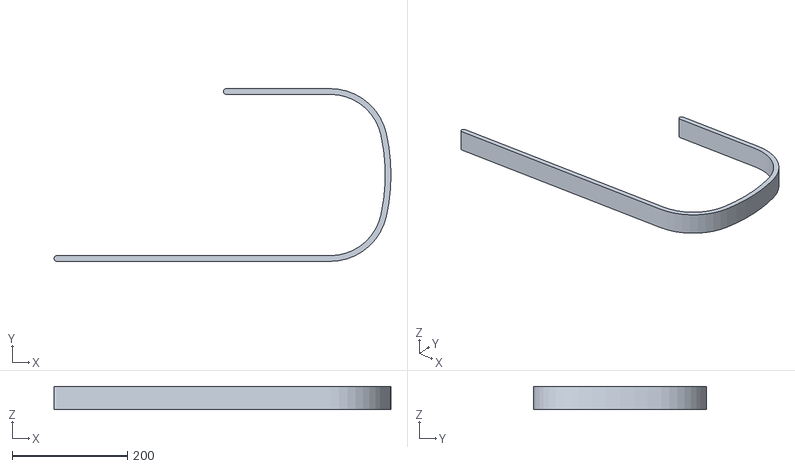
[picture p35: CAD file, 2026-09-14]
Solidworks_Design/New folder/curve.STL
585.2 x 300.0 x 40.0

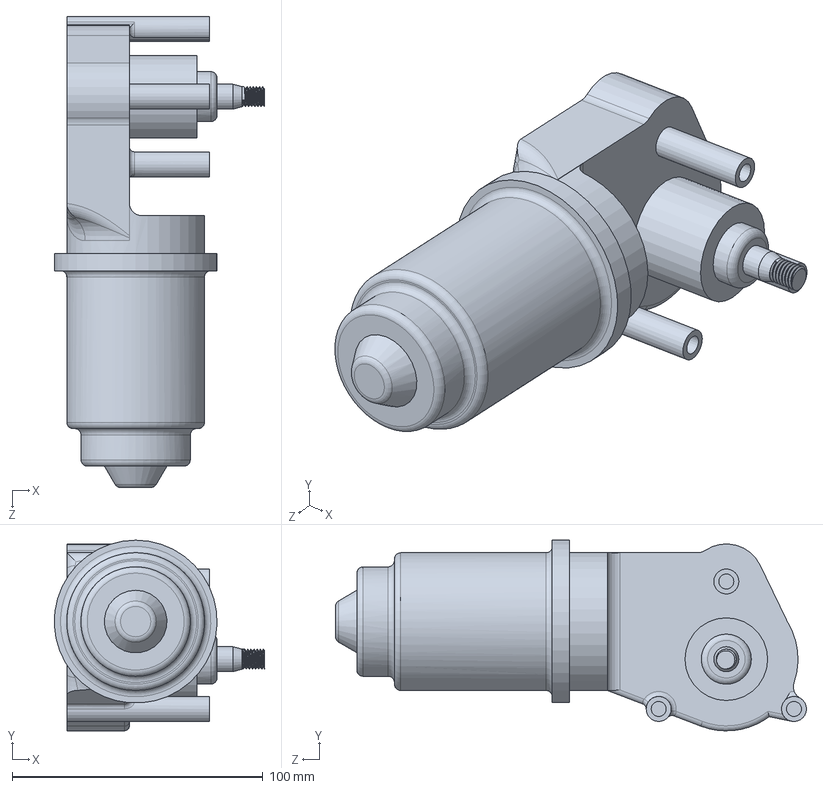
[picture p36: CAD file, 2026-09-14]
Solidworks_Design/Graduation Project 2 (LAST)/Motor 100rpmn1.SLDPRT
84.0 x 76.1 x 188.0 mm

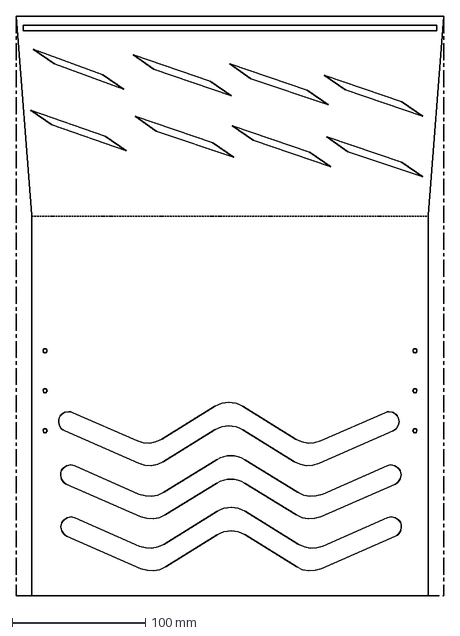
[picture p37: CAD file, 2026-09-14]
Solidworks_Design/Graduation Project 2 n/DXF/face.DXF
320.8 x 435.1 mm

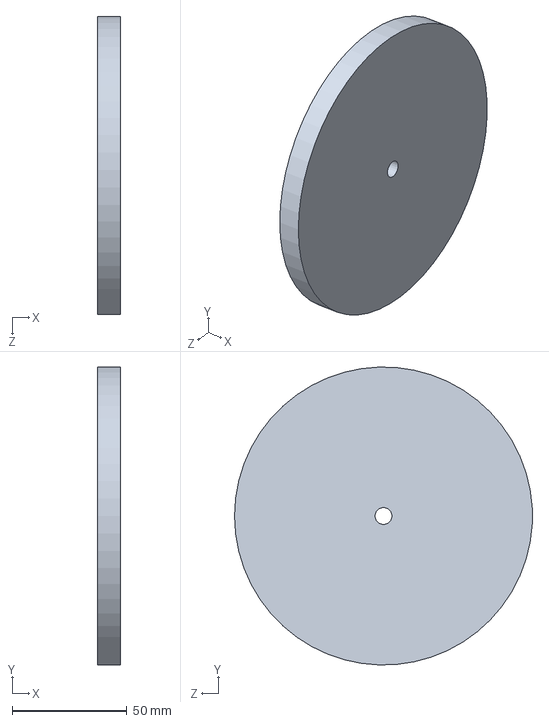
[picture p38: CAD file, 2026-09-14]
Solidworks_Design/Graduation Project 2 n/Graduation Project 2/Part3.SLDPRT
10.0 x 129.9 x 130.0 mm

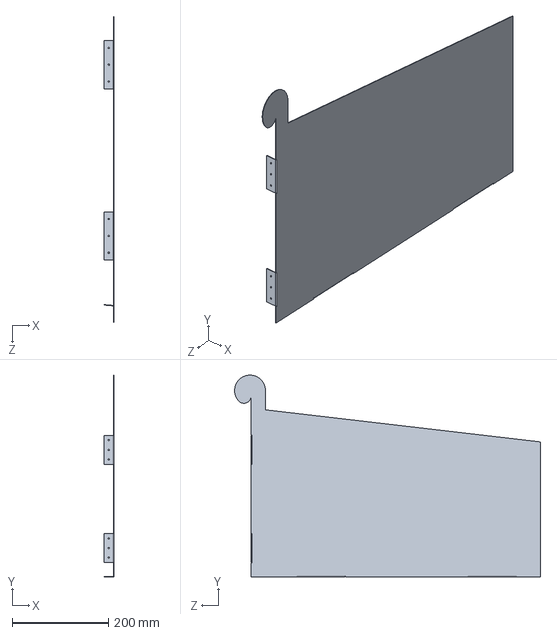
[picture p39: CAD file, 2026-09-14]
Solidworks_Design/Graduation Project 2/R. side follow.SLDPRT
21.0 x 418.7 x 634.4 mm

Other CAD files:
Solidworks_Design/Graduation Project/assembly final project.SLDASM
Solidworks_Design/Graduation Project 2 n/Graduation Project 2/Base Base Follow.SLDPRT
Solidworks_Design/Graduation Project 2 (LAST)/Base Base Follow New.DXF
Solidworks_Design/Graduation Project 2 (LAST)/Base Base Follow lastttt.DXF
Solidworks_Design/Graduation Project 2 (LAST)/Base Base Follow.DXF
Solidworks_Design/Graduation Project 2 (LAST)/Base Follow.DXF
Solidworks_Design/Graduation Project 2 (LAST)/Base Follow.SLDPRT
Solidworks_Design/Graduation Project 2 (LAST)/Closing Box.SLDPRT
Solidworks_Design/Graduation Project 2 (LAST)/L. Side Follow.SLDPRT
Solidworks_Design/Graduation Project 2 (LAST)/R. side follow.SLDDRW
Solidworks_Design/Graduation Project 2 (LAST)/R. side follow.SLDPRT
Solidworks_Design/Graduation Project 2 (LAST)/assembly final project.SLDASM
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

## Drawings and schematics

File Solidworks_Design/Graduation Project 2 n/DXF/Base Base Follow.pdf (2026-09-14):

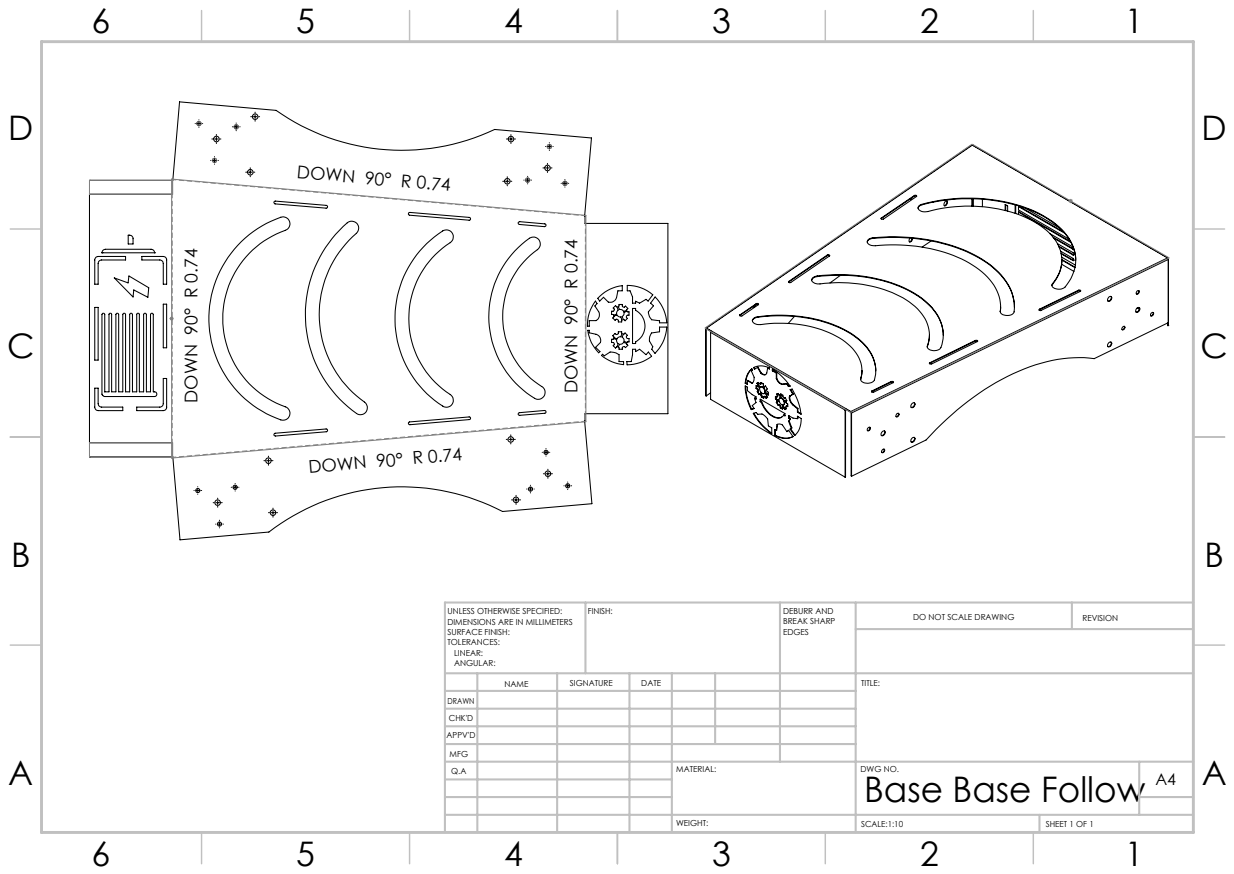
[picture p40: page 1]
DOWN 90° R 0.74; FINISH:; DEBURR AND; BREAK SHARP; DO NOT SCALE DRAWING; REVISION; SCALE:1:10; SHEET 1 OF 1

UNLESS OTHERWISE SPECIFIED:
DIMENSIONS ARE IN MILLIMETERS
SURFACE FINISH:
TOLERANCES:
LINEAR:
ANGULAR:

NAME | SIGNATURE | DATE | | | | TITLE:

DRAWN
CHK'D
APPV'D
MFG
Q.A | | | | MATERIAL: | DWG NO. Base Base Follow | A4

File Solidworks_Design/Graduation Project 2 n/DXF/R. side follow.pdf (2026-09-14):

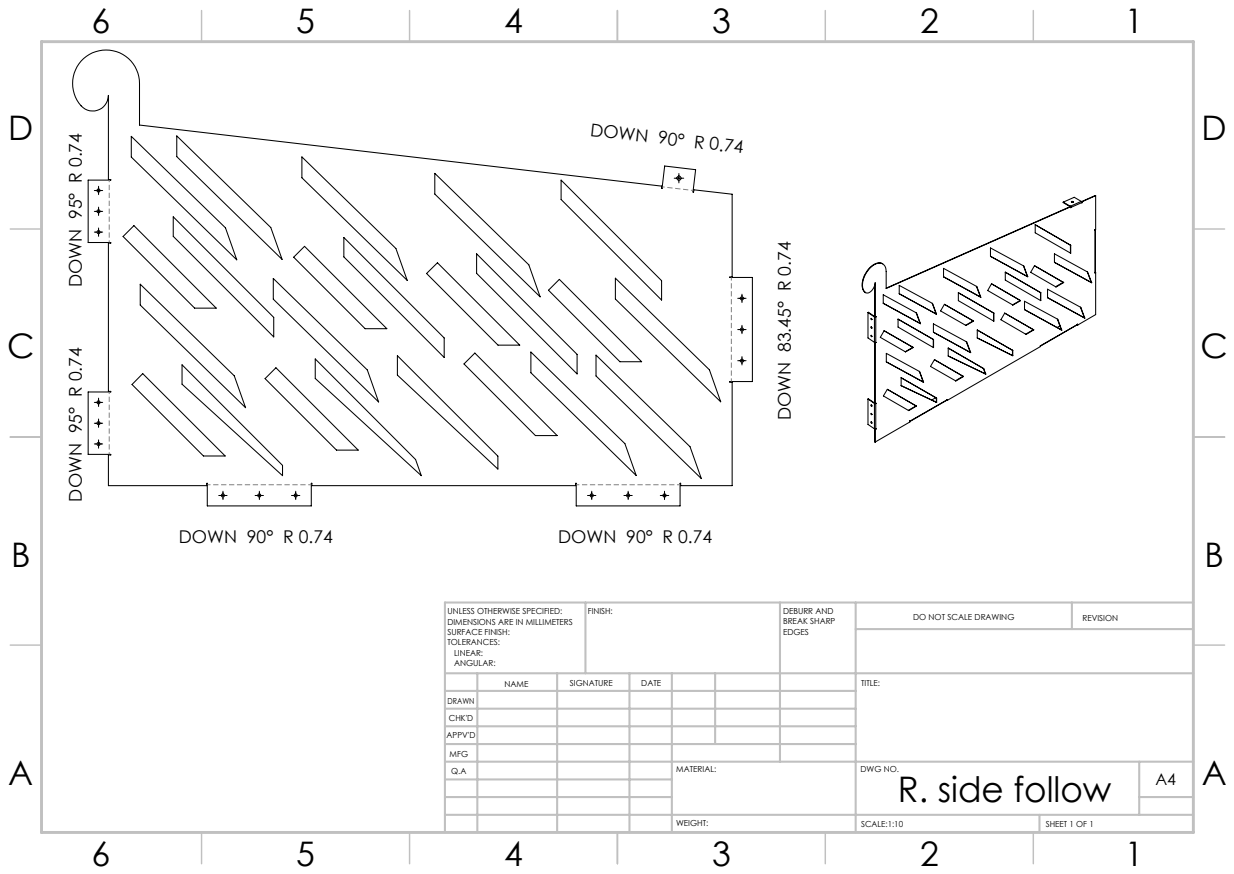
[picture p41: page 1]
DOWN 83.45° R 0.74; DOWN 90° R 0.74; DOWN 95° R 0.74 DOWN 95° R 0.74; FINISH:; DEBURR AND; BREAK SHARP; DO NOT SCALE DRAWING; REVISION; SCALE:1:10; SHEET 1 OF 1

UNLESS OTHERWISE SPECIFIED:
DIMENSIONS ARE IN MILLIMETERS
SURFACE FINISH:
TOLERANCES:
LINEAR:
ANGULAR:

NAME | SIGNATURE | DATE | | | | TITLE:

DRAWN
CHK'D
APPV'D
MFG
Q.A | | | | MATERIAL: | DWG NO. R. side follow | A4

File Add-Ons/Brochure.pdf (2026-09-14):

Stay Close, Move Freely

Key Features of the Cart

AI-Powered Gesture Recognition
Hands-free, intuitive control.

Real-time safety for smooth navigation.

Obstacle Detection & Avoidance

Enhances mobility and independence.

Autonomous User Following

Designed for various terrains with extended usability.

Durable & Portable

Provide smooth movement with a capacity of up to 62.7 kg

CAD-based design for durability and ease of assembly

Processes real-time data to follow users and avoid obstacles.

Rechargeable battery system ensures seamless operation

How It Works

Innovative Technologies

Enables hand gesture tracking using advanced algorithms.

Infrared and ultrasonic sensors ensure obstacle-free operation

We are a team of ambitious engineers from the Faculty of Engineering, Mansoura University, specializing in Mechatronics. Our mission is to leverage modern technology to create solutions that make life easier for those in need.

Mobility issues among the elderly and disabled significantly limit independence and quality of life. Traditional aids often lack adaptability and ease of use.

The "Follow-Me Cart" combines artificial intelligence, computer vision, and durable mechanical design to offer hands-free mobility assistance.

The Automated Follow-Me Cart is an innovative assistive mobility solution designed to empower elderly and disabled individuals. Using AI and computer vision, the cart autonomously follows users, recognizes hand gestures, and avoids obstacles in real-time. It is durable, portable, and adaptable to various environments such as homes and stores.

The integrated mobile app enhances usability by enabling battery monitoring, cart content tracking, store mapping, and remote control. This project combines advanced technology and engineering to promote independence, convenience, and inclusivity.

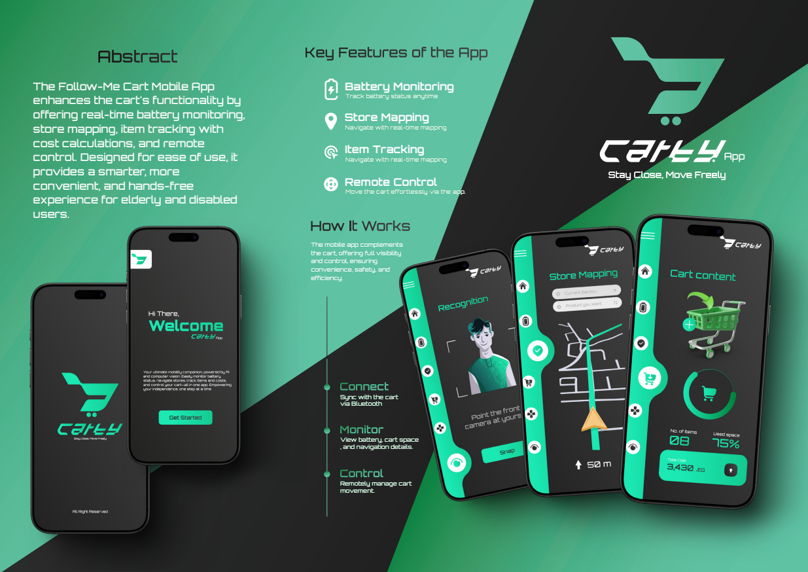
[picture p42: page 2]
App

The Follow-Me Cart Mobile App
enhances the cart's functionality by
offering real-time battery monitoring,
store mapping, item tracking with
cost calculations, and remote
control. Designed for ease of use, it
provides a smarter, more
convenient, and hands-free
experience for elderly and disabled
users.

Battery Monitoring
Track battery status anytime
Store Mapping
Navigate with real-time mapping
Item Tracking
Remote Control
Move the cart effortlessly via the app.

The mobile app complements
the cart, offering full visibility
and control, ensuring
convenience, safety, and
efficiency.

Sync with the cart
via Bluetooth

View battery, cart space
, and navigation details.

Remotely manage cart
movement.

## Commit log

2026-09-14 Commit to main
    [Assem1.SLDASM, Base Base Follow New.DXF, Base Base Follow lastttt.DXF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]
2026-09-14 Add project PowerPoint using Git LFS
